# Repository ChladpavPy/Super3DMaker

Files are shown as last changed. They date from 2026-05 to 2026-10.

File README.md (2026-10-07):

# Super3DMaker Controller Board

So first I want to explain, why I started this project. I had an old Profi3DMaker 3D printer at home, which was not used for a long time, mainly because of the hardware, which was just outdated. Because the printer had electronics probably from years like 2012 and older, it was my idea to bring it again to life, because the tech of 3D printing and electronics changed a lot. The 3D printer actually works, but does not stand a chance to modern machines which would be even cheaper based on the materials. Back in 2012, this printer was high-end and one of the most expensive 3D printers, you could get, because of the high quality aluminium frame, but because the technology changed so rapidly, it is just unreliable and prints items badly now, when compared to new 3d printers, which are also cheap. And because it is mainly and electronics issue, I realized that I could build my own new 3D printer board for this 3D printer and bring it again to life, so I started new Project.

The first stage was actually reverse-engineering the old board and studying as much possible of how modern 3d printers work.

A custom mainboard designed to replace the old electronics in my 3D printer. Built to handle klipper high speed kinematics and communicate directly with a Raspberry Pi Zero 2W. Designed entirely from scratch in KiCad 10.

## The Build and Integration Phase

After receiving the manufactured PCB from JLCPCB, the project transitioned into the physical build phase. This involved soldering all components and integrating the new board into the chassis. 

The most intensive part was the software setup and calibration. I configured Klipper and the Raspberry Pi, and spent a significant amount of time getting the `printer.cfg` right. This meant dialing in the correct motor parameters, gear ratios, and microsteps through trial and error and reverse engineering.

### Results and Current Limitations

The custom STM32F407VET6 board works perfectly and successfully replaces the old ATmega setup. Klipper brings many modern features compared to the old Marlin firmware. Thanks to the new TMC2209 drivers, the printer is now significantly quieter during operation.

However, the build process revealed several mechanical limitations of the original Profi3DMaker chassis that the new electronics alone cannot fix:
* **Z-Axis Noise:** Despite the silent drivers, the Z-axis still makes mechanical grinding noises, indicating a physical issue with the leadscrews or bearings.
* **Heated Bed Inefficiency:** The massive original heated bed takes around an hour to reach just 70°C. 
* **Toolhead Weight:** The older extruder system is extremely heavy, limiting printing speeds and precision. 

To fully utilize the new controller board's capabilities, I have designed a completely new mount for a modern toolhead. This can be actually directly mounted on the chassis. However, this will only add weight if I don't disassemble the moving carriage from the tubes, which requires practically disassembling the entire printer, which I plan to do as a future upgrade. This would also require creating another model which would replace the previous aluminium carriage on the tubes. For now, the goal of successfully designing, building, and running a custom controller board has been achieved.

## Firmware

Since this board is built around a custom STM32F407VET6 microcontroller, it runs on the open-source [Klipper](https://github.com/Klipper3d/klipper) firmware. Instead of writing custom kinematic calculations from scratch, the firmware setup uses a printer configuration file. You can find the complete pin-mapping and configuration file (`printer.cfg`), along with the original dumped `.srec` firmware files used to reverse-engineer the correct gear ratios and microsteps, ready in the `Firmware` folder. You can also access all the other original files for this 3D printer by registering on the 3D Factories website.
## Project Features

* **Microcontroller:** STM32F407VET6 (100-pin, 32-bit ARM Cortex-M4)
* **Stackup:** 4-Layer PCB (Signal / GND / GND / Signal) for internal routing and better EMI shielding
* **Stepper Drivers:** 6x UART-controlled TMC2209 sockets
* **Power:** 24V main input with dual LM2596S buck converters (5V and 3.3V rails)
* **Connectivity:** USB-B for main communication, native Raspberry Pi UART interface
* **Displays:** Standard 10-pin IDC EXP1 and EXP2 headers for legacy 12864 or modern SPI BTT Mini12864 displays
* **Hardware Interlock:** Laser module power logically tied to the high-current heated bed circuit to prevent simultaneous power draw

* And more other...

### Video Demos

https://github.com/user-attachments/assets/c8a4d6e0-8937-4ded-b093-ac17ca0ef771

https://github.com/user-attachments/assets/72c90019-3e0b-4c00-92d0-47ec632bfb1b

https://github.com/user-attachments/assets/8aad29d0-d306-4471-a87c-c93d6b09ec2d

LIS2DW accelometer calibration

https://github.com/user-attachments/assets/c06aa969-909b-4192-8ba1-088b3594a9f0

CR Touch Bed Mesh

https://github.com/user-attachments/assets/029f4fde-3b9d-4758-a506-7faca7a6295e

## Gallery

### Build Preview
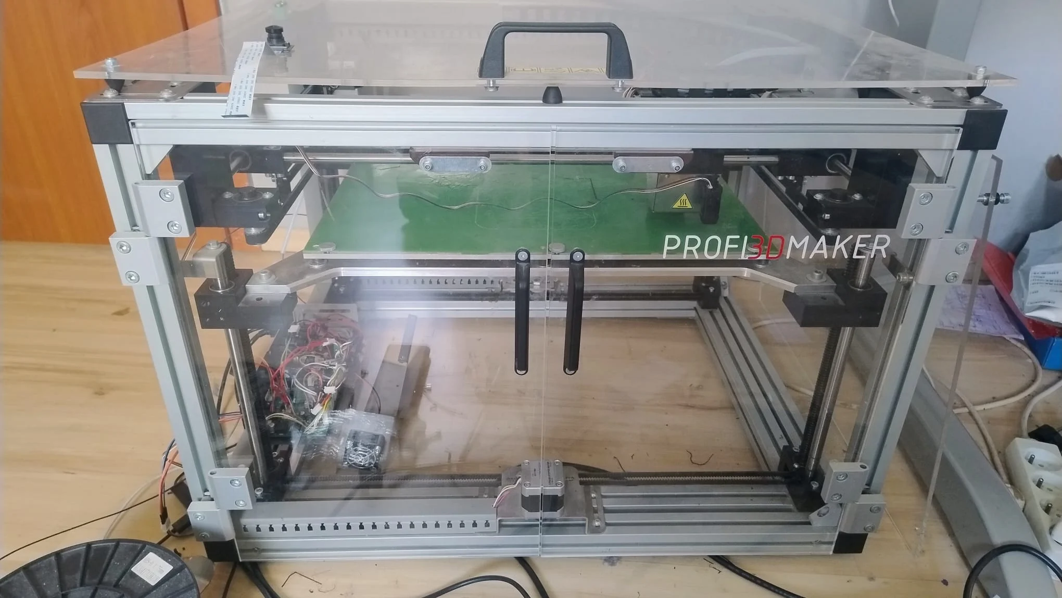
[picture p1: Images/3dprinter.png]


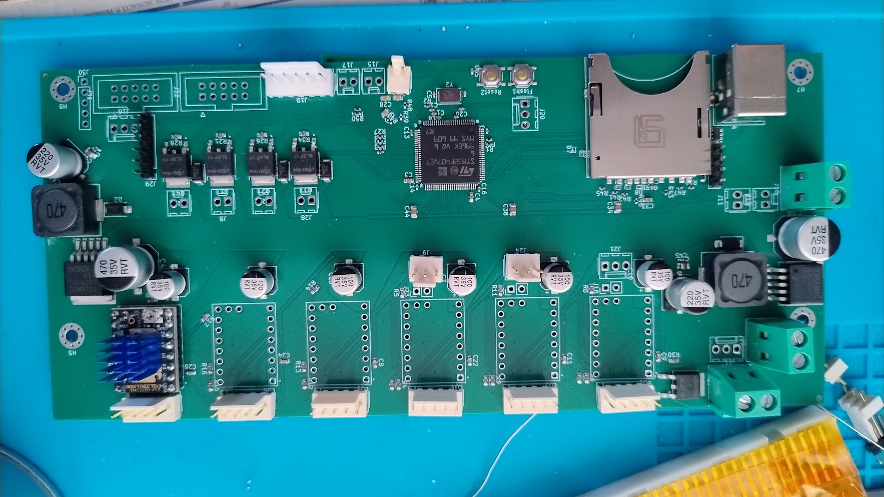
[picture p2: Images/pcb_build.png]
Build Preview


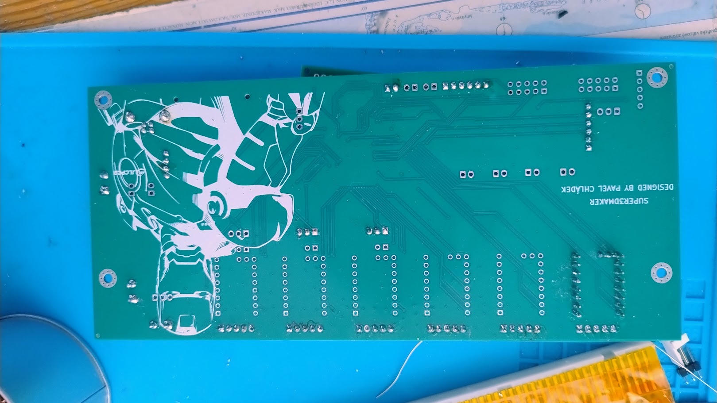
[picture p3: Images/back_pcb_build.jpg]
Build Preview


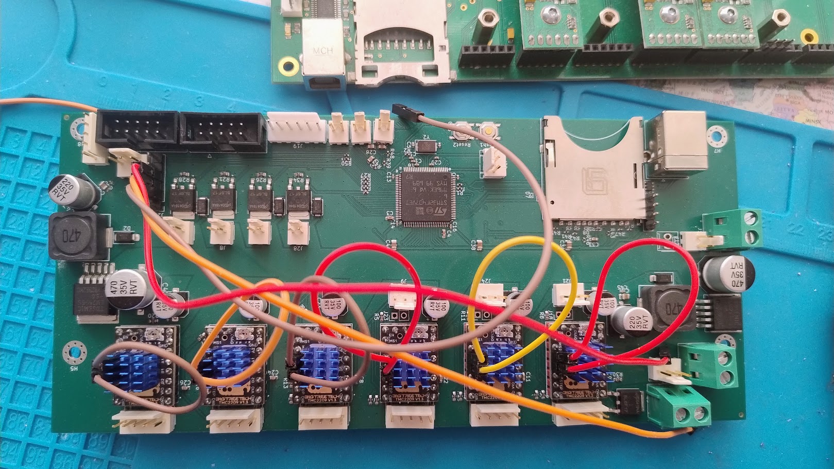
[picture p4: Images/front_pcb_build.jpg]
Build Preview


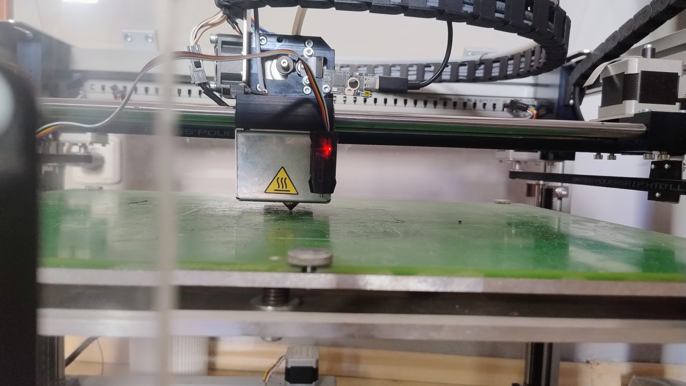
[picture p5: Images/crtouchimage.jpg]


### Printing
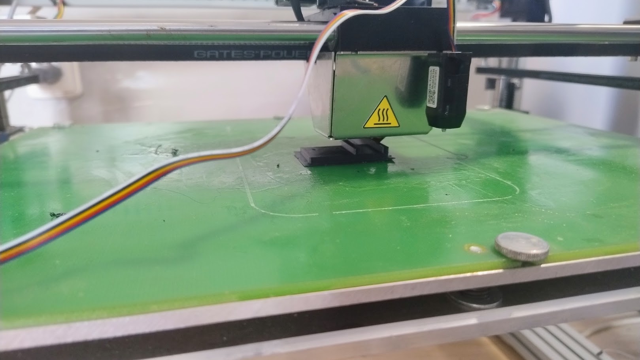
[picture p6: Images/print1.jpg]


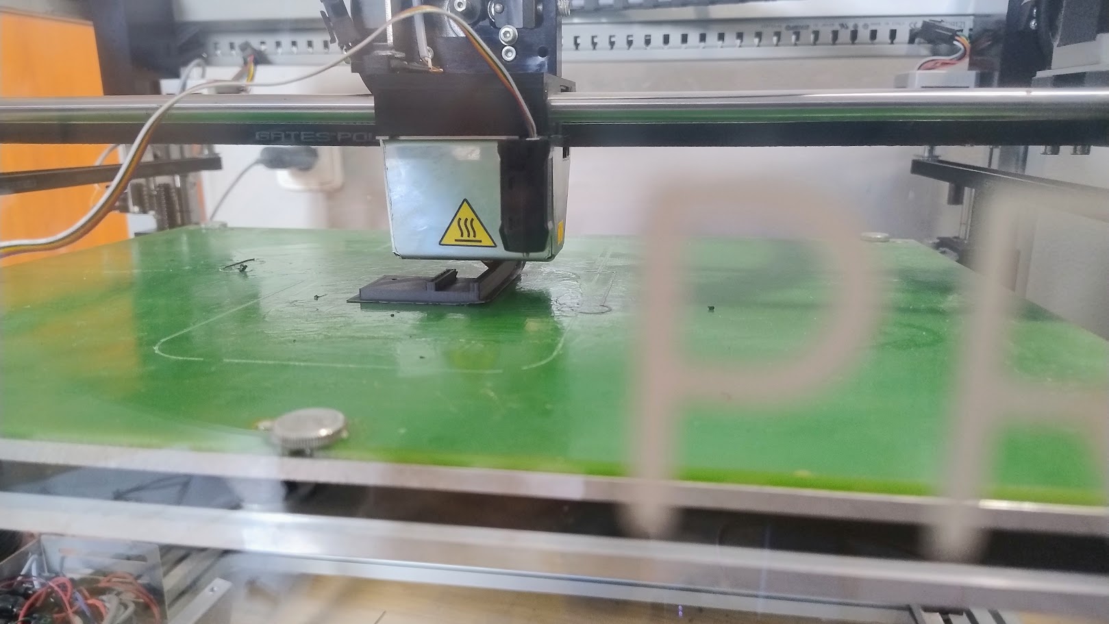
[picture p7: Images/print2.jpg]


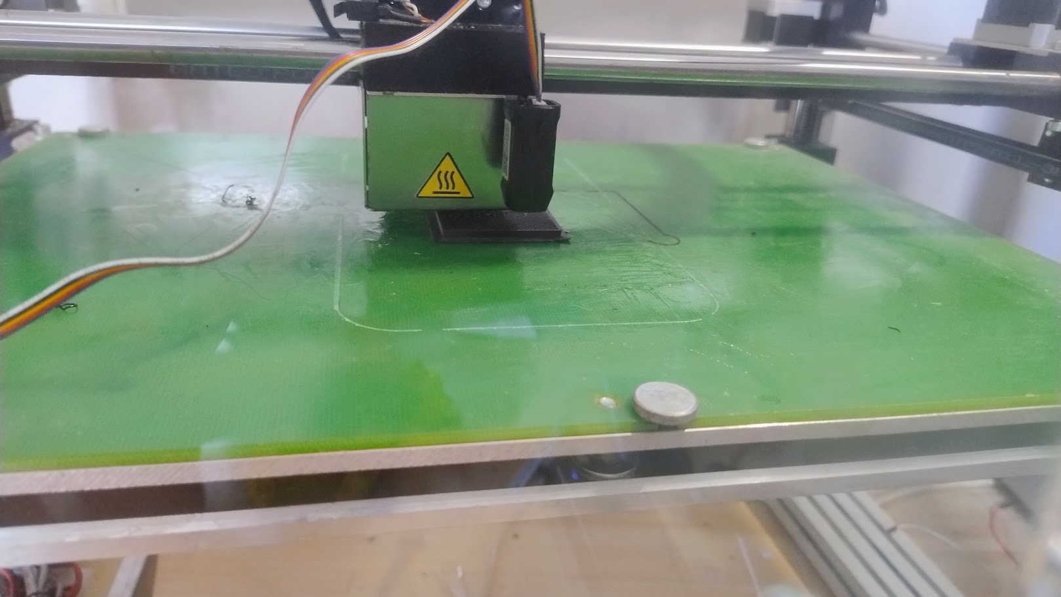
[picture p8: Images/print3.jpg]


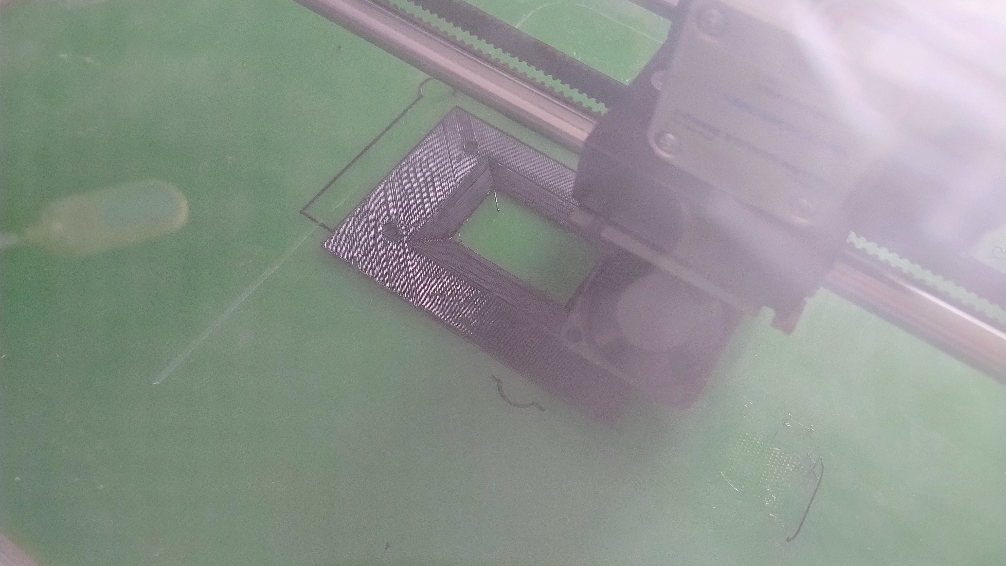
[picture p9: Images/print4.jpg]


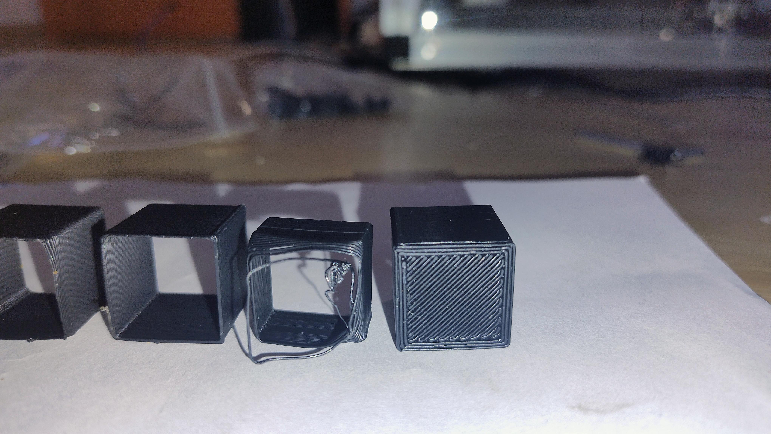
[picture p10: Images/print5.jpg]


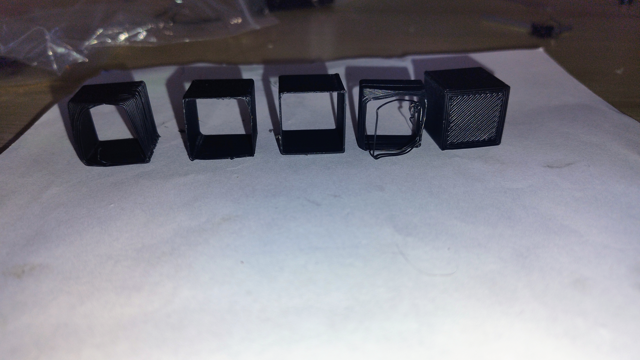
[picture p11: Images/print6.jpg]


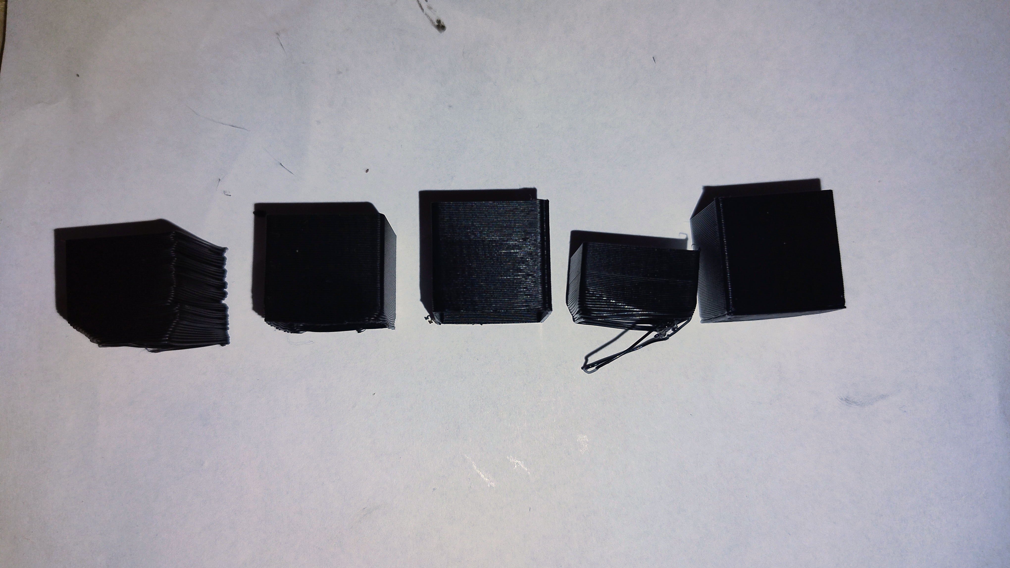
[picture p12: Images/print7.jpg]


### 3D PCB Render
PCB 3D

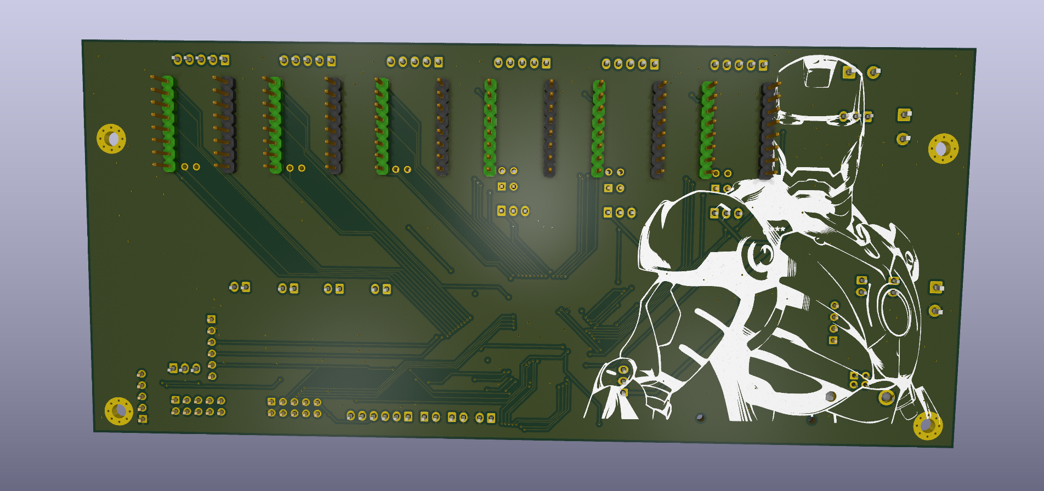
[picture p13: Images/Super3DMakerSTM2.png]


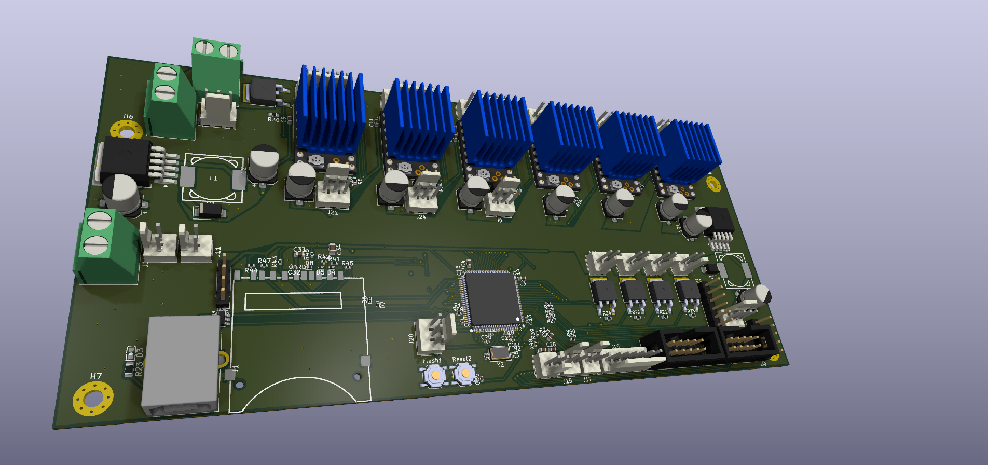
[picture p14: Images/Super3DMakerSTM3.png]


### PCB Routing
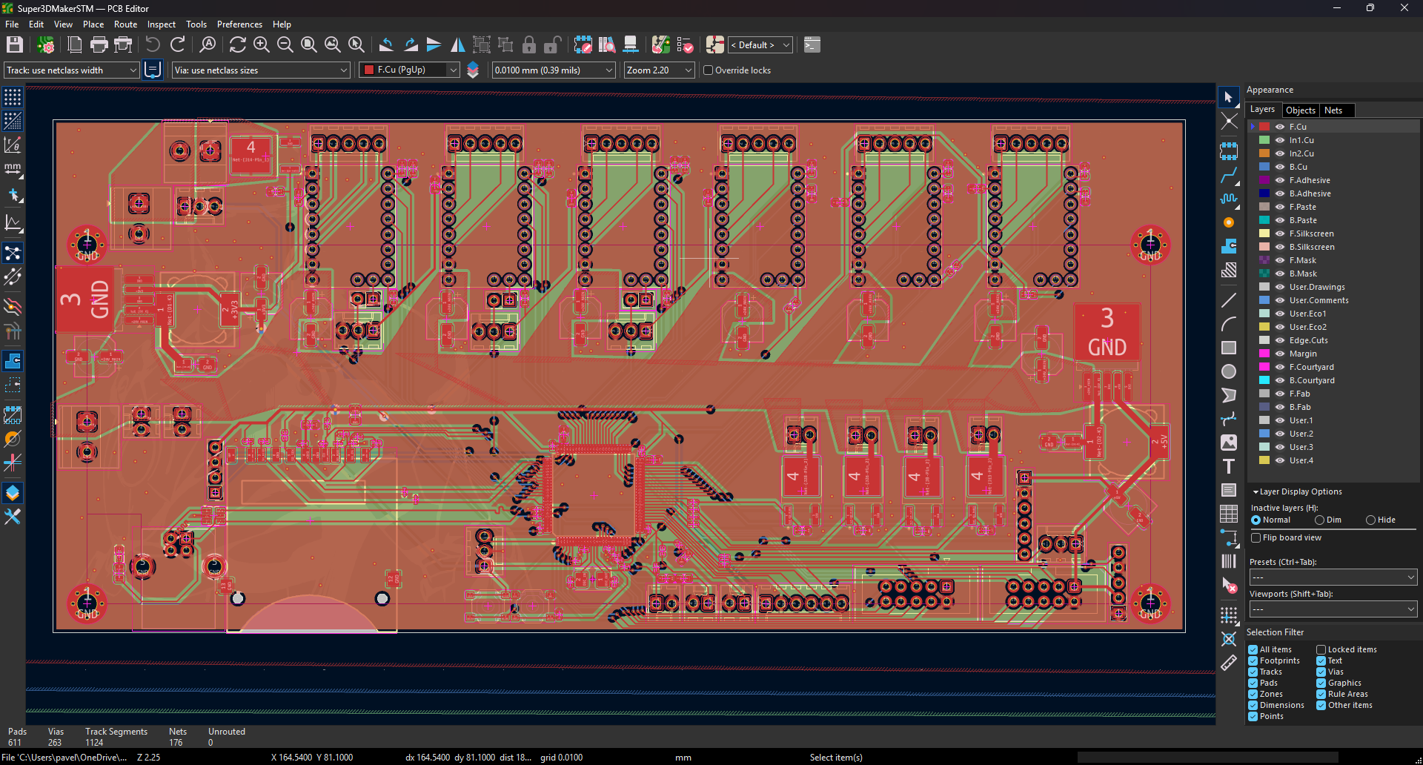
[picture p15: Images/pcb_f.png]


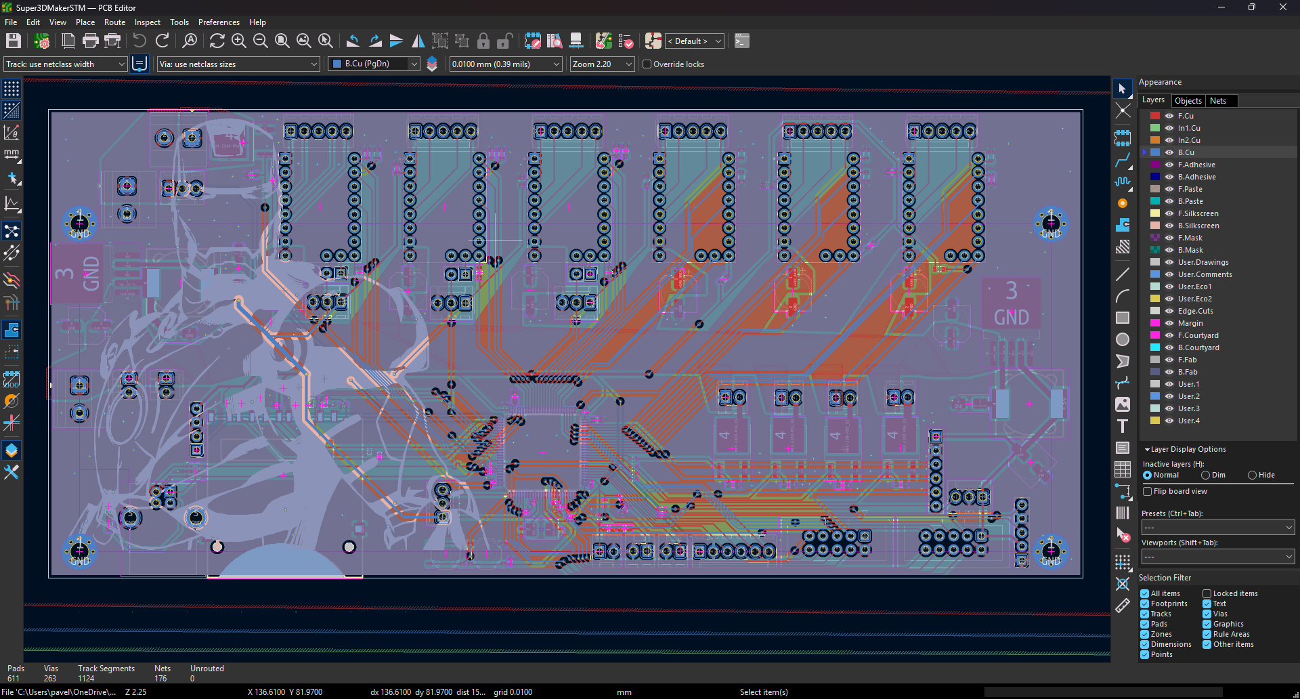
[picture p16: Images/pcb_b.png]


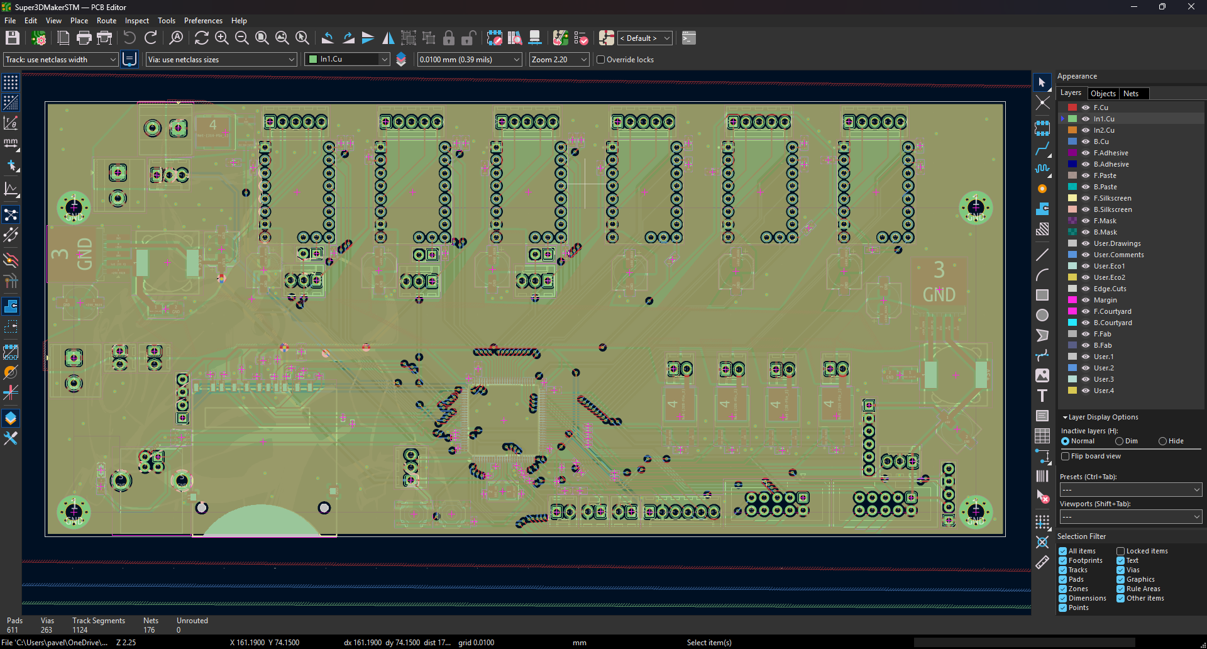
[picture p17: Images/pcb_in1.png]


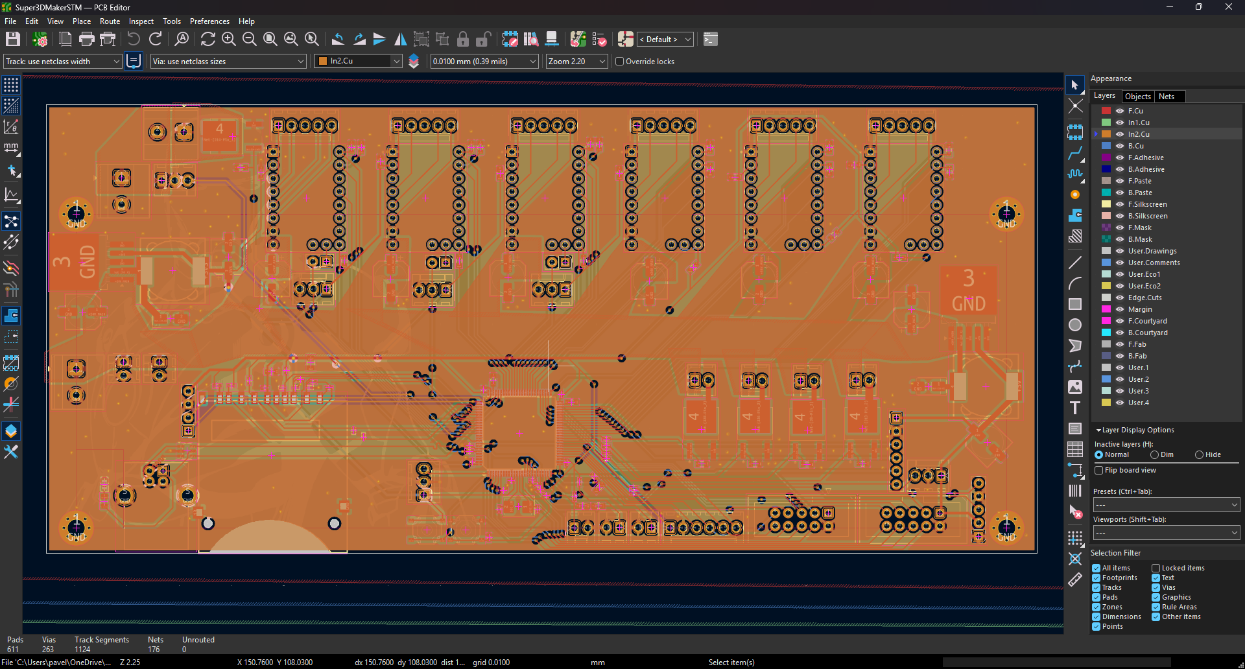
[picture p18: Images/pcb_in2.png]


### Schematic
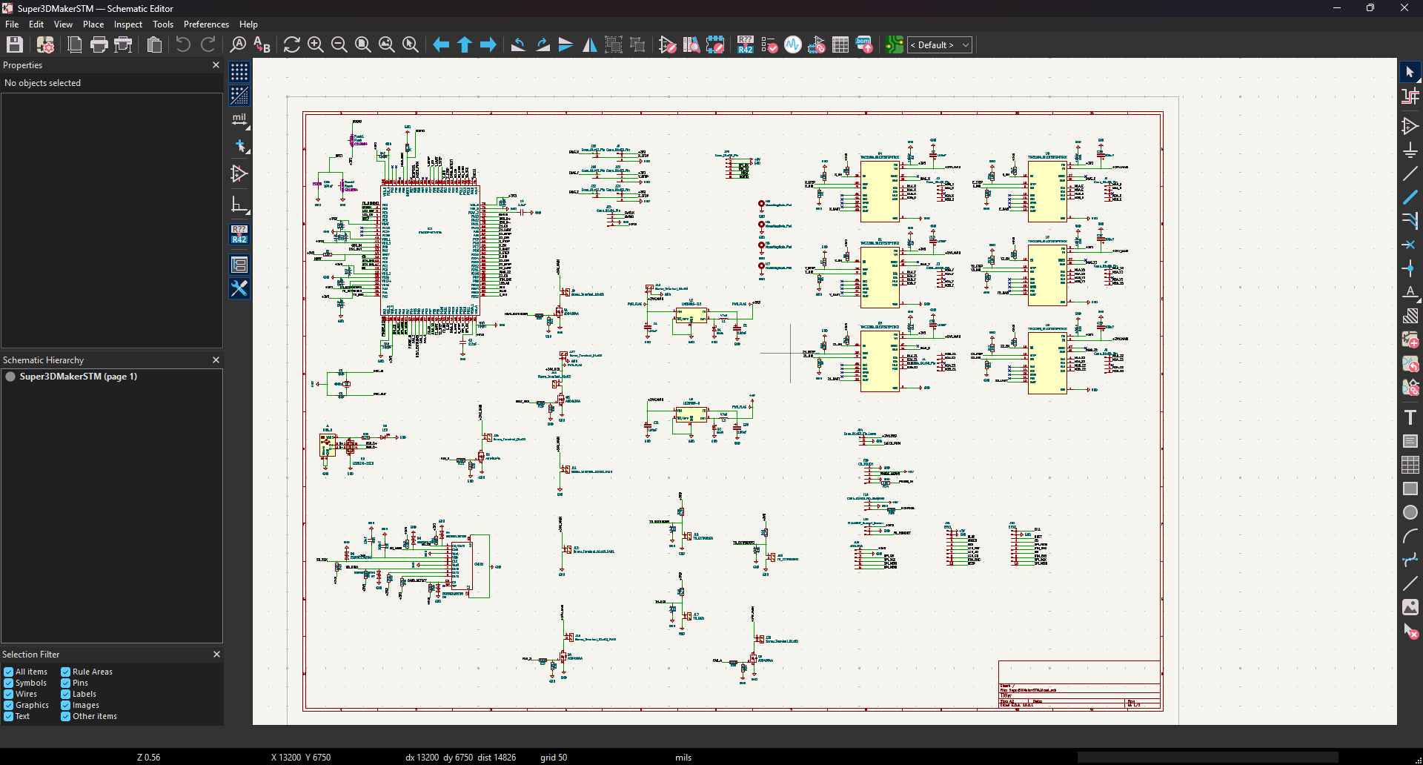
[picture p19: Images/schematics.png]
Schematic


---

## Bill of Materials (BOM)

| Component | Qty | Purpose / Description | Price (USD) | Link / Distributor |
| :--- | :---: | :--- | :--- | :--- |
| **Custom PCBA (Mainboard)** | 2 | Custom designed 4-layer STM32 controller board. Fully assembled via JLCPCB SMT (minus the THT USB-B connector which will be soldered manually to avoid mechanical case collisions). | ~$137.67 | JLCPCB - This is the price for 2 assembled boards to keep the price as low as possible. |
| **BIQU H2 V2S REVO** | 1 | Ultra-lightweight direct drive extrusion system with rapid-change nozzle capability. Replaces the current heavy toolhead, significantly reducing weight on the massive 400mm X-axis for faster, vibration-free printing. | $151.45 | [Allegro](https://allegro.cz/produkt/extruder-btt-biqu-h2-v2s-revo-direct-drive-1-75-mm-ce63ae7c-46b2-4eb6-95d3-a286495341f3?offerId=12801178318) |
| **ADXL345 3-Axis Accelerometer** | 2 | Essential for Klipper's Input Shaping calibration. It measures the physical resonance frequencies of the X and Y axes, allowing the firmware to actively cancel out vibrations during high-speed printing and eliminate ringing/ghosting on the printed parts. | $2.88 | [AliExpress](https://a.aliexpress.com/_EH7aAa2) |
| **CR-Touch (Auto Bed Leveling)** | 1 | Provides automatic high-precision mesh bed leveling. It compensates for any slight warping of the print bed and ensures a perfect first layer every time by measuring the distance between the nozzle and the build surface at multiple points. | $20.00 | [AliExpress](https://a.aliexpress.com/_EvwN6HC) |
| **BigTreeTech TMC2209 V1.3** | 6 | These are high-performance silent motor drivers required for the custom motherboard. They feature StealthChop technology for near-silent operation and StallGuard for sensorless homing, eliminating the need for physical limit switches. | $19.25 | [AliExpress](https://a.aliexpress.com/_EILgKrG) |
| **Raspberry Pi Zero 2W** | 1 | Serves as the main host computer for the custom 3D printer. It runs the Klipper firmware ecosystem and its web interface (Mainsail/Fluidd), performs heavy kinematics calculations, and sends precise hardware commands to the custom-designed STM32 motherboard via serial/USB connection. | $20.17 | [Rpishop](https://rpishop.cz/raspberry-pi-zero/4311-raspberry-pi-zero-2-w.html) |

### Mechanical and Assembly

| Item | Qty | Specification | Purpose |
| :--- | :---: | :--- | :--- |
| **Original Aluminum Case** | 1 | The heavy original printer chassis | I had to reverse engineer the mounting holes and connector distances, because I could not get the original CAD files. It was a nightmare but it fits within like 4.7mm of the board edge now. |
| **M3 Screws** | 4 | Standard mounting hardware | Securing the PCB to the chassis standoffs. |
- For the case of the 3d printer - Profi3DMaker case is used

## How to Build and Flash Firmware

If you want to replicate this custom controller board for your own Profi3DMaker or similar 3D printer, follow these steps:

1. **PCB Fabrication & Assembly:** Use the provided Gerber files (found in the repository) to manufacture the board. Most SMD components are assembled by JLCPCB, but you will need to manually solder the THT USB-B connector, terminal blocks, and JST headers.
2. **STM32 Bootloader & Klipper Firmware:**
   * Connect the board to your PC via USB-B while holding the BOOT/RESET buttons to enter DFU mode.
   * Compile Klipper for the `STM32F407VET6` chip using `make menuconfig` on your Raspberry Pi Zero 2W.
   * Flash the compiled `klipper.bin` to the STM32 using STM32CubeProgrammer.
3. **Raspberry Pi Integration:** Connect the Raspberry Pi Zero 2W to the board using the dedicated UART pins for serial communication.
4. **Configuration:** Upload the provided `printer.cfg` (found in the `/Firmware` folder) to your Klipper interface (Mainsail/Fluidd) and verify motor directions and sensor readings.
That is all, thank you for reading!

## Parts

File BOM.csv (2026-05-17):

Reference | Qty | Value | DNP | Exclude from BOM | Exclude from Board | Footprint | Datasheet | MNF PART NUMBER | LCSC
C1,C2,C7,C10,C21,C23,C25,C27,C30,C31 | 10 | 100uF |  |  |  | Capacitor_SMD:CP_Elec_6.3x7.7 |  | C3352 | C3352
C3,C4 | 2 | 2.2uF |  |  |  | Capacitor_SMD:C_0603_1608Metric |  | C23630 | C23630
C5,C6 | 2 | 33pF |  |  |  | Capacitor_SMD:C_0402_1005Metric |  | C1562 | C1562
C8,C9,C11,C22,C24,C26 | 6 | 100nF |  |  |  | Capacitor_SMD:C_0603_1608Metric |  | C14663 | C14663
C12,C13,C14,C15,C16,C17,C18,C19,C20 | 9 | 100nF |  |  |  | Capacitor_SMD:C_0402_1005Metric |  | C307331 | C307331
C28,C29,C36 | 3 | 10uF |  |  |  | Capacitor_SMD:C_0603_1608Metric |  | C14663 | C14663
C32 | 1 | 100nF |  |  |  | Capacitor_SMD:C_0402_1005Metric |  | C14663 | C14663
C33 | 1 | 10uF |  |  |  | Capacitor_SMD:C_0603_1608Metric |  | C19702 | C19702
C34 | 1 | 10uF |  |  |  | Capacitor_SMD:C_0805_2012Metric |  | C14663 | C14663
C35 | 1 | 100nF |  |  |  | Capacitor_SMD:C_0402_1005Metric |  | C1525 | C1525
CARD1 | 1 | SD_CARD |  |  |  | Moje_knihovna:SD_KARTA_OPRAVENA | https://item.szlcsc.com/datasheet/SD-006M/136893.html | C125615 | C125615
D1,D2 | 2 | SS54 |  |  |  | Diode_SMD:D_SMA |  | C22452 | C22452
D3 | 1 | LED |  |  |  | LED_SMD:LED0603-RD |  | C2286 | C2286
D4,D5,D6,D7,D8 | 5 | ESD9B3.3ST5G |  |  |  | Diode_SMD:D_SOD-923 | https://www.onsemi.com/pub/Collateral/ESD9B-D.PDF | C96512 | C96512
Flash1 | 1 | Flash |  |  |  | Button_Switch_SMD:SW_Push_1P1T_XKB_TS-1187A |  | C318884 | C318884
IC1 | 1 | STM32F407VET6 |  |  |  | Moje_knihovna:LQFP100-0.5-13.8X13.8MM | https://www.st.com/resource/en/datasheet/stm32f405zg.pdf | C28730 | C28730
J1 | 1 | USB_B |  |  |  | Connector_USB:USB_B_OST_USB-B1HSxx_Horizontal |  | C498173 | C498173
J2,J3,J4,J5,J6,J7 | 6 | Conn_01x05_Pin |  |  |  | Connector_Molex:Molex_KK-254_AE-6410-05A_1x05_P2.54mm_Vertical
J8,J26,J28 | 3 | Screw_Terminal_01x02 |  |  |  | Connector_Molex:Molex_KK-254_AE-6410-02A_1x02_P2.54mm_Vertical
J9,J21,J24 | 3 | Conn_01x03_Pin |  |  |  | Connector_Molex:Molex_KK-254_AE-6410-03A_1x03_P2.54mm_Vertical
J10,J14,J27 | 3 | Screw_Terminal_01x02 |  |  |  | TerminalBlock_Phoenix:TerminalBlock_Phoenix_MKDS-1 | 5-2-5.08_1x02_P5.08mm_Horizontal
J11 | 1 | Screw_Terminal_01x02_FAN0 |  |  |  | Connector_Molex:Molex_KK-254_AE-6410-02A_1x02_P2.54mm_Vertical
J12 | 1 | Screw_Terminal_01x02_FAN1 |  |  |  | Connector_Molex:Molex_KK-254_AE-6410-02A_1x02_P2.54mm_Vertical
J13 | 1 | Screw_Terminal_01x02_FAN2 |  |  |  | Connector_Molex:Molex_KK-254_AE-6410-02A_1x02_P2.54mm_Vertical
J15 | 1 | TH_EXTRUDER |  |  |  | Connector_Molex:Molex_KK-254_AE-6410-02A_1x02_P2.54mm_Vertical
J16 | 1 | Conn_01x03_Pin_Neopixel |  |  |  | Connector_Molex:Molex_KK-254_AE-6410-03A_1x03_P2.54mm_Vertical
J17 | 1 | TH_BED |  |  |  | Connector_Molex:Molex_KK-254_AE-6410-02A_1x02_P2.54mm_Vertical
J18,J22,J23 | 3 | Conn_01x02_Pin |  |  |  | Connector_PinHeader_2.54mm:PinHeader_1x02_P2.54mm_Vertical
J19 | 1 | ADXL345 |  |  |  | Connector_Molex:Molex_KK-254_AE-6410-06A_1x06_P2.54mm_Vertical
J20 | 1 | FILAMENT_Runout_Sensor |  |  |  | Connector_Molex:Molex_KK-254_AE-6410-03A_1x03_P2.54mm_Vertical
J25 | 1 | Conn_01x04_Pin |  |  |  | Connector_PinHeader_2.54mm:PinHeader_1x04_P2.54mm_Vertical
J29 | 1 | Conn_01x06_Pin |  |  |  | Connector_PinHeader_2.54mm:PinHeader_1x06_P2.54mm_Vertical
J30 | 1 | CR_TOUCH |  |  |  | Connector_PinHeader_2.54mm:PinHeader_1x05_P2.54mm_Vertical
J31 | 1 | EPX1 |  |  |  | Connector_IDC:IDC-Header_2x05_P2.54mm_Vertical
J32 | 1 | EPX2 |  |  |  | Connector_IDC:IDC-Header_2x05_P2.54mm_Vertical
J33 | 1 | TH_EXTRUDER2 |  |  |  | Connector_Molex:Molex_KK-254_AE-6410-02A_1x02_P2.54mm_Vertical
J34 | 1 | Conn_01x03_Pin_Laser |  |  |  | Connector_Molex:Molex_KK-254_AE-6410-03A_1x03_P2.54mm_Vertical
L1,L2 | 2 | 47uH |  |  |  | Inductor_SMD:IND-SMD_L12.3-W12.3 |  | C9906 | C9906
Q1,Q2,Q3,Q4,Q5 | 5 | AOD4184A |  |  |  | Moje_knihovna:DPAK228P994X240-4N |  | C99124 | C99124
R1,R2,R24,R41,R42,R43,R44,R45,R46,R47 | 10 | 10K |  |  |  | Resistor_SMD:R_0402_1005Metric |  | C25804 | C25804
R3,R4,R5,R6,R7,R8,R9,R10,R11,R12,R13,R14,R15,R16,R17,R18,R19,R20,R21,R26,R28,R30,R34 | 23 | 10K |  |  |  | Resistor_SMD:R_0603_1608Metric |  | C25804 | C25804
R22,R25,R27,R29,R33,R50 | 6 | 330R |  |  |  | Resistor_SMD:R_0402_1005Metric |  | C25104 | C25104
R23 | 1 | 4.7K |  |  |  | Resistor_SMD:R_0805_2012Metric |  | C17673 | C17673
R39,R40,R48 | 3 | 4.7K |  |  |  | Resistor_SMD:R_0402_1005Metric |  | C25900 | C25900
Reset2 | 1 | Reset |  |  |  | Button_Switch_SMD:SW_Push_1P1T_XKB_TS-1187A |  | C318884 | C318884
U1,U3,U4,U5,U6,U7 | 6 | TMC2209_SILENTSTEPSTICK |  |  |  | Moje_knihovna:MODULE_TMC2209_SILENTSTEPSTICK
U2 | 1 | LM2596S-3.3 |  |  |  | Package_TO_SOT_SMD:TO-263-5_TabPin3 | http://www.ti.com/lit/ds/symlink/lm2596.pdf | C42421958 | C42421958
U8 | 1 | LM2596S-5 |  |  |  | Package_TO_SOT_SMD:TO-263-5_TabPin3 | http://www.ti.com/lit/ds/symlink/lm2596.pdf | C42421959 | C42421959
U9 | 1 | USBLC6-2SC6 |  |  |  | Package_TO_SOT_SMD:SOT-23-6 | https://www.st.com/resource/en/datasheet/usblc6-2.pdf | C7519 | C7519
Y2 | 1 | 8MHz |  |  |  | Crystal:Crystal_SMD_5032-2Pin_5.0x3.2mm |  | C115962 | C115962
H5,H6,H7,H8 | 4 | MountingHole |  |  |  | MountingHole_3.2mm_M3_Pad_Via

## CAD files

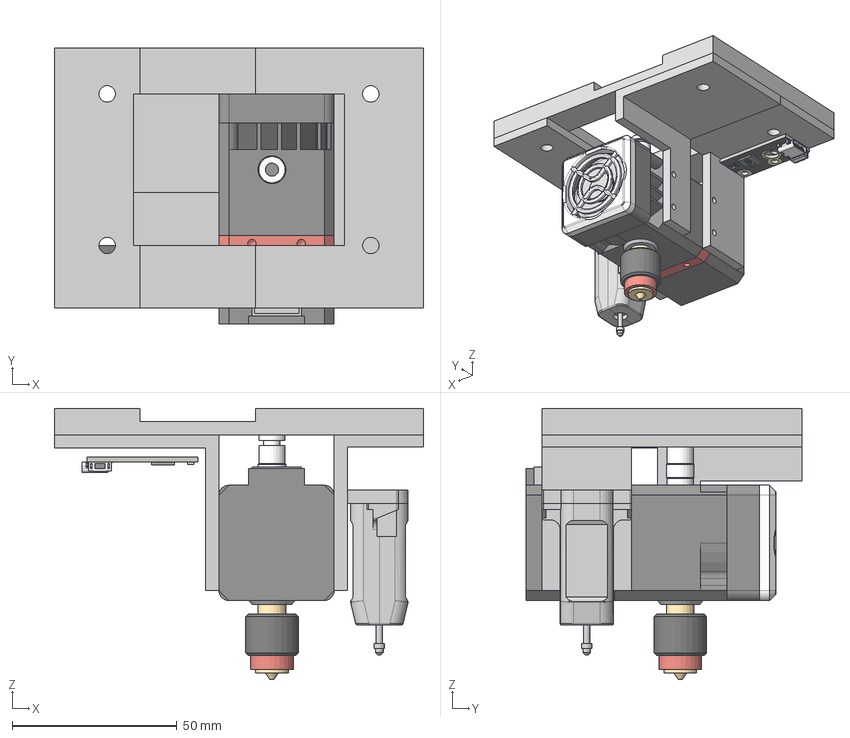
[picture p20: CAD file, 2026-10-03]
3D_Models/Super3dmaker_ToolheadV1.step
112.0 x 83.9 x 82.3 mm

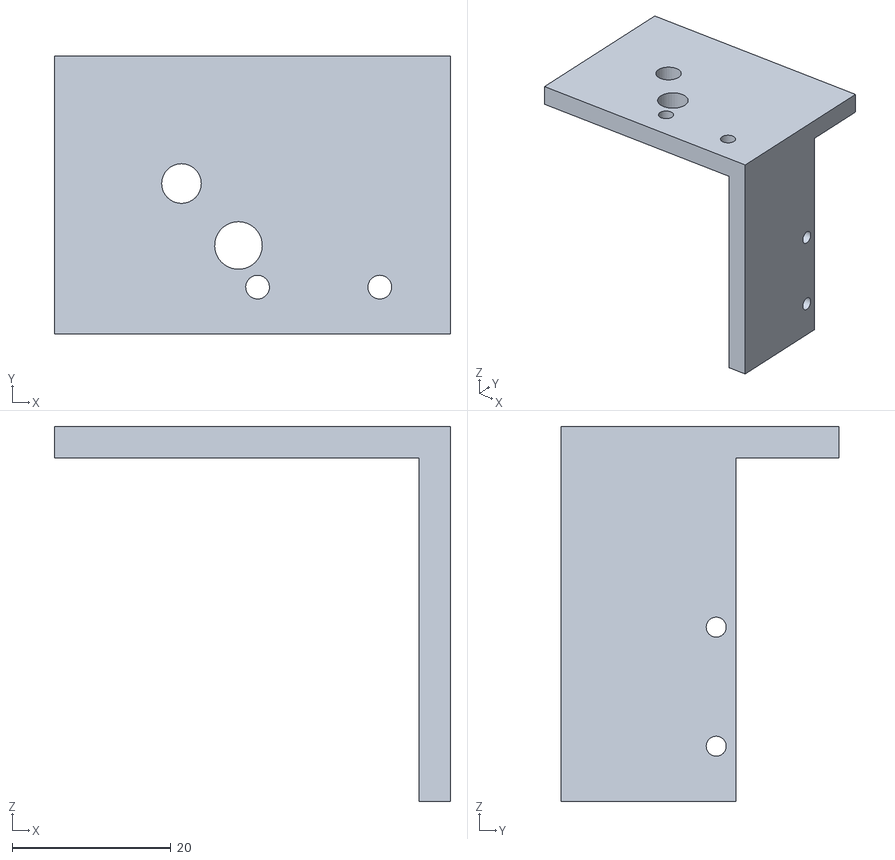
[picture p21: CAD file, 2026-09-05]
3D_Models/left_plate1.stl
49.9 x 35.1 x 47.3

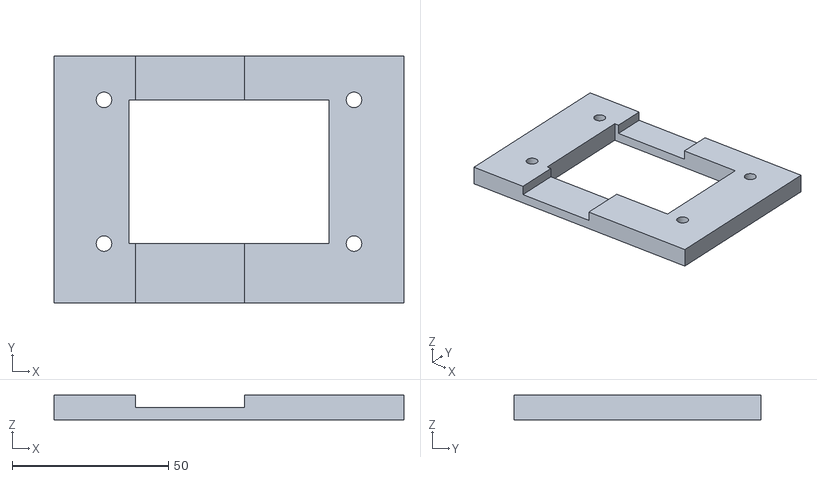
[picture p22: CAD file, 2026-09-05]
3D_Models/Top_plate.stl
112.0 x 79.0 x 8.00

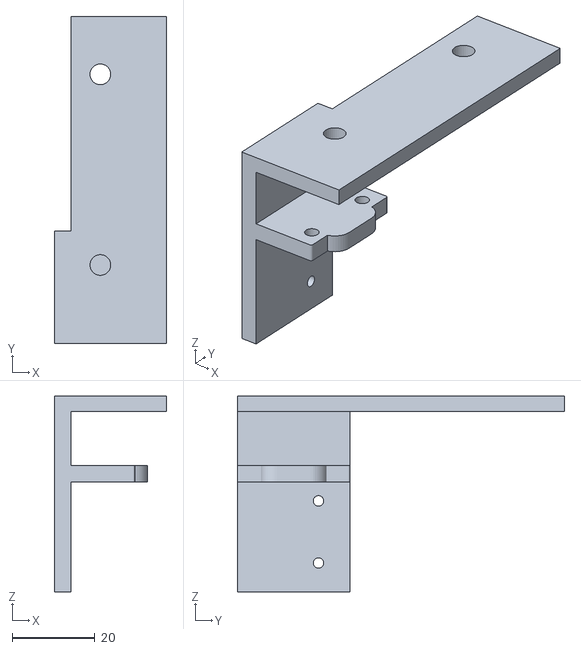
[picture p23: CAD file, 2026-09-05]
3D_Models/Right_plate.stl
27.1 x 79.0 x 47.3

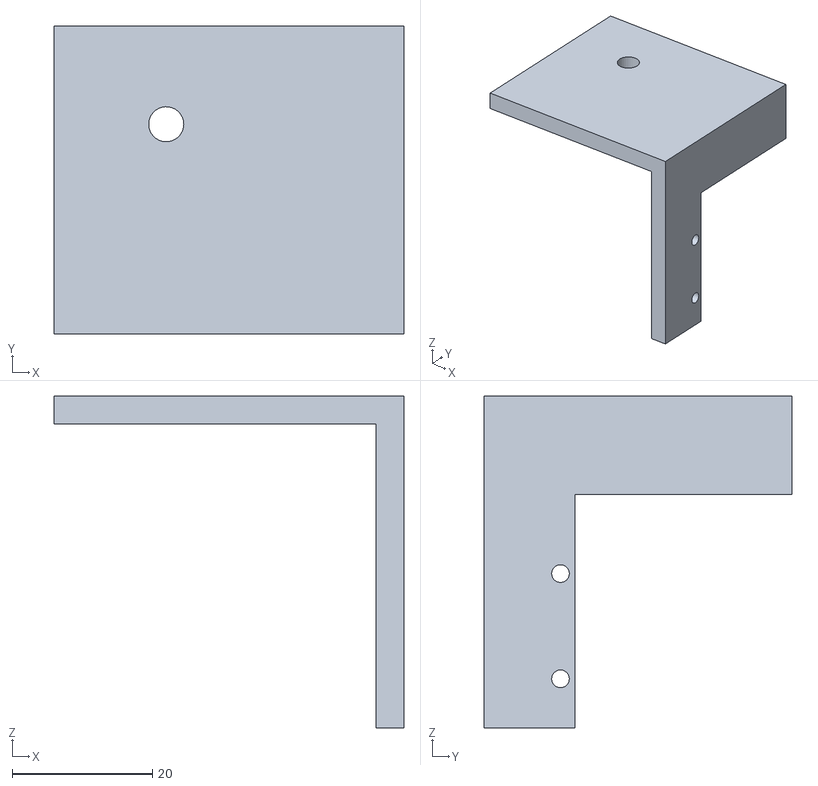
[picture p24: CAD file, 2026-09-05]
3D_Models/left_plate2.stl
49.9 x 43.9 x 47.3

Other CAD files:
3D_Models/Super3dmaker_ToolheadV1.f3z

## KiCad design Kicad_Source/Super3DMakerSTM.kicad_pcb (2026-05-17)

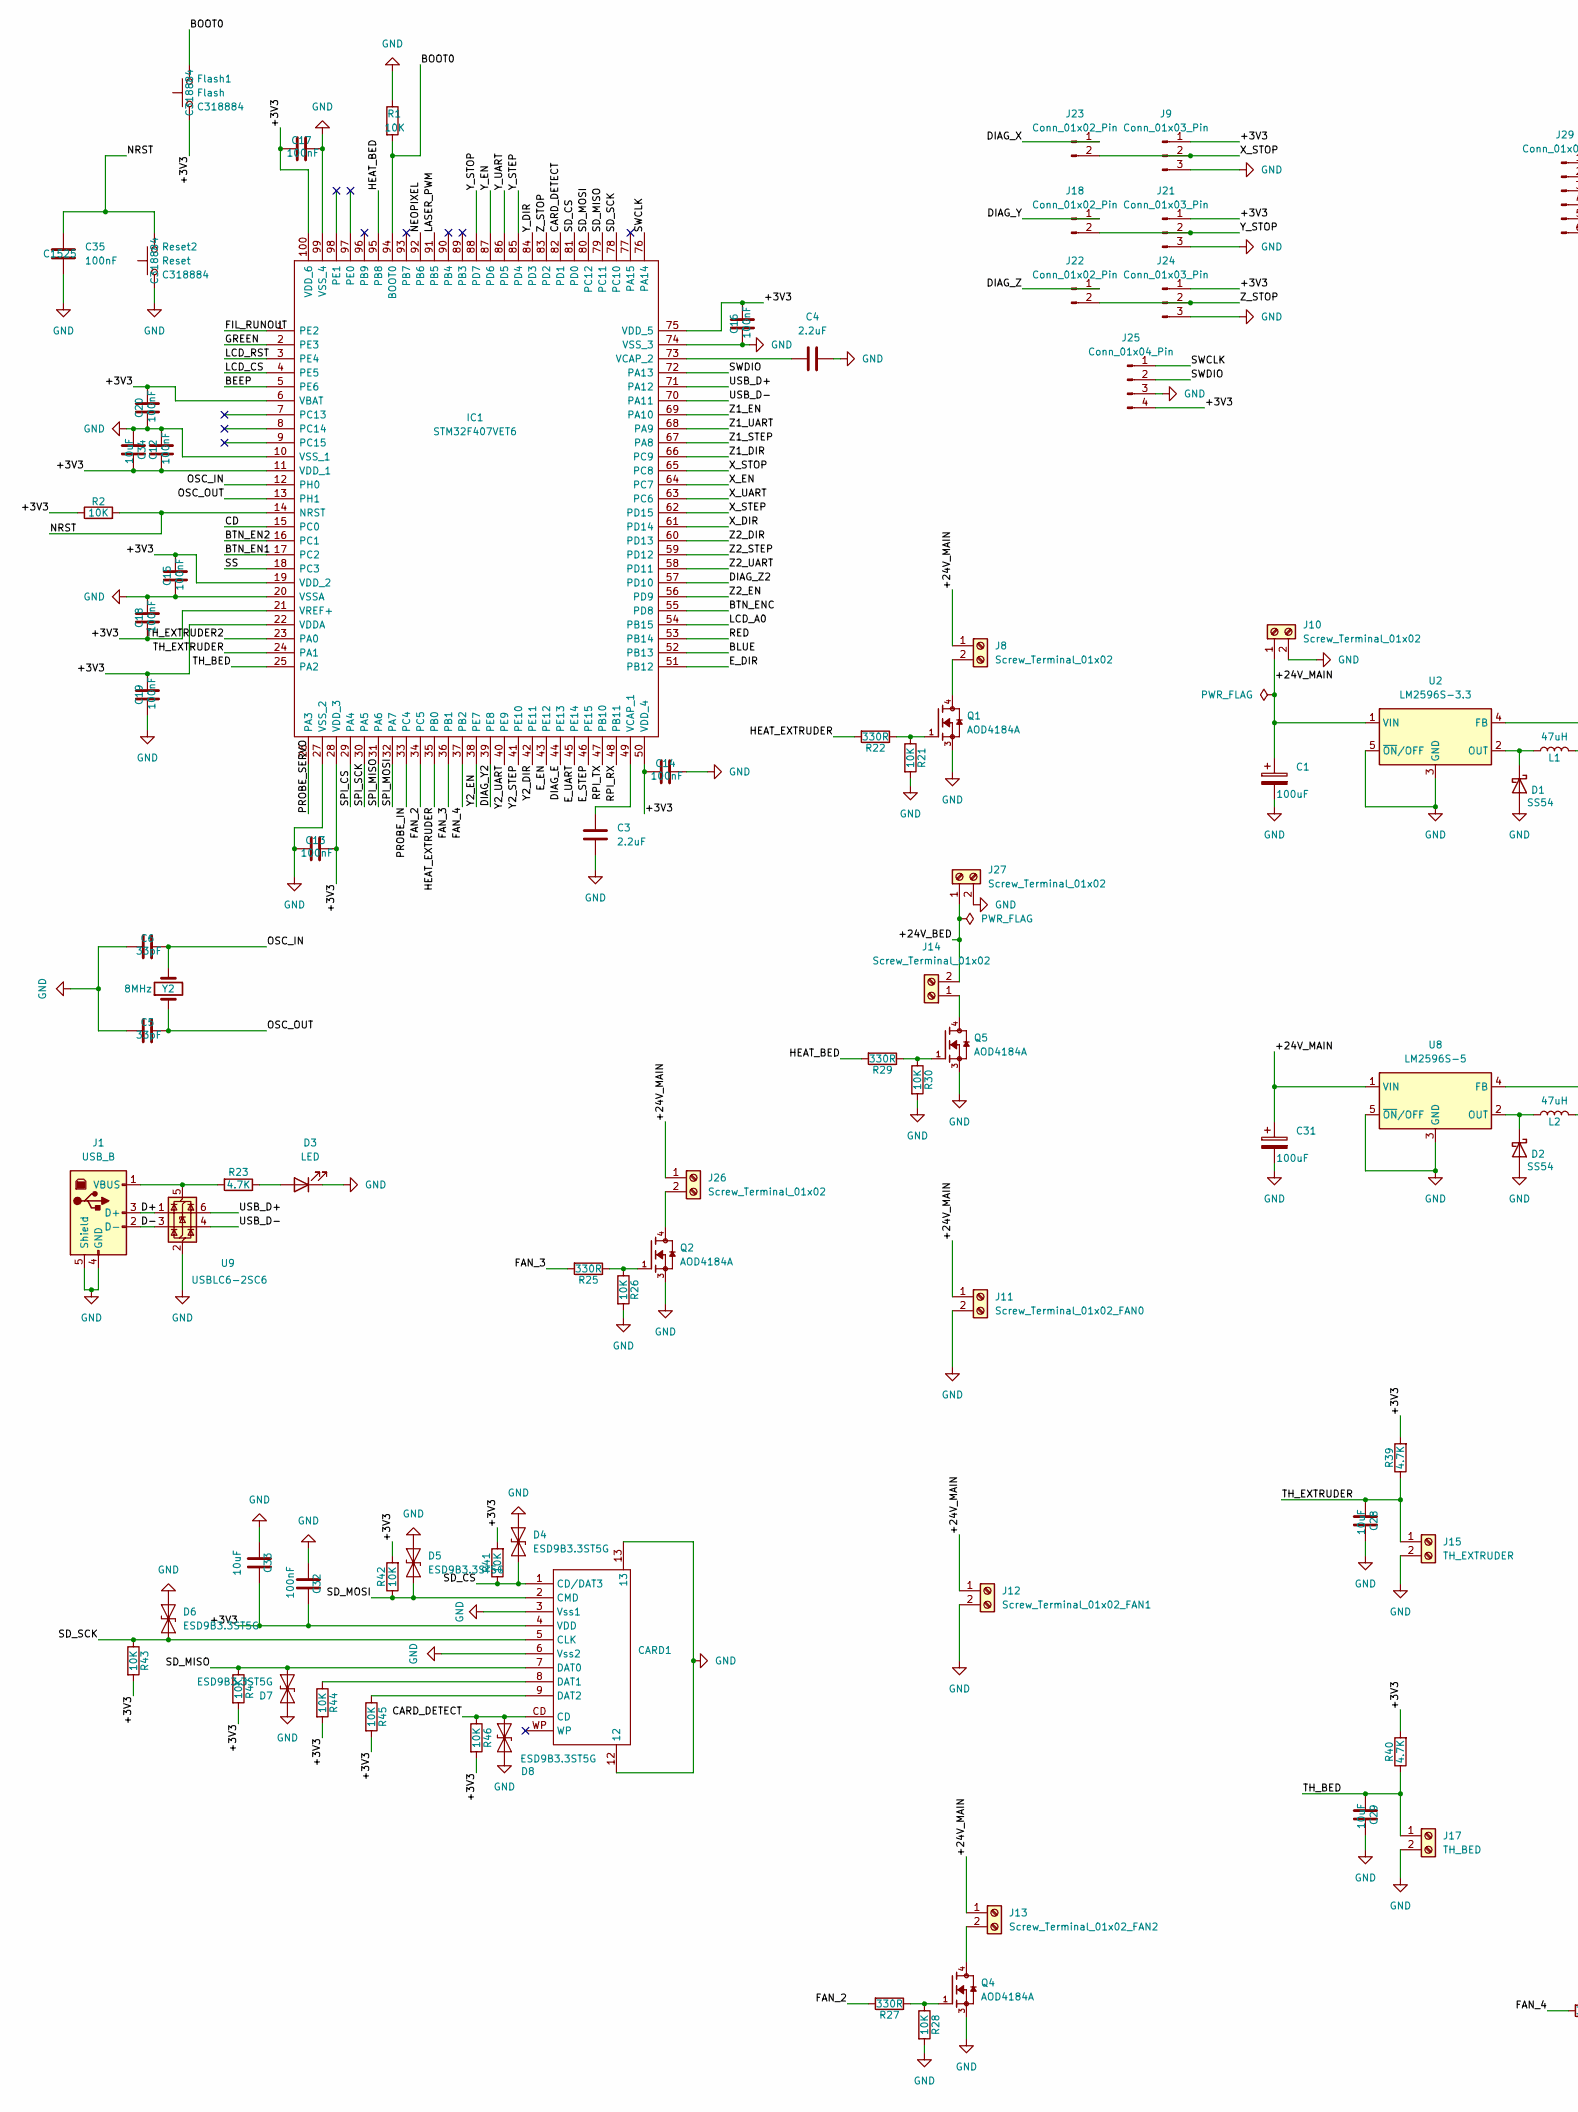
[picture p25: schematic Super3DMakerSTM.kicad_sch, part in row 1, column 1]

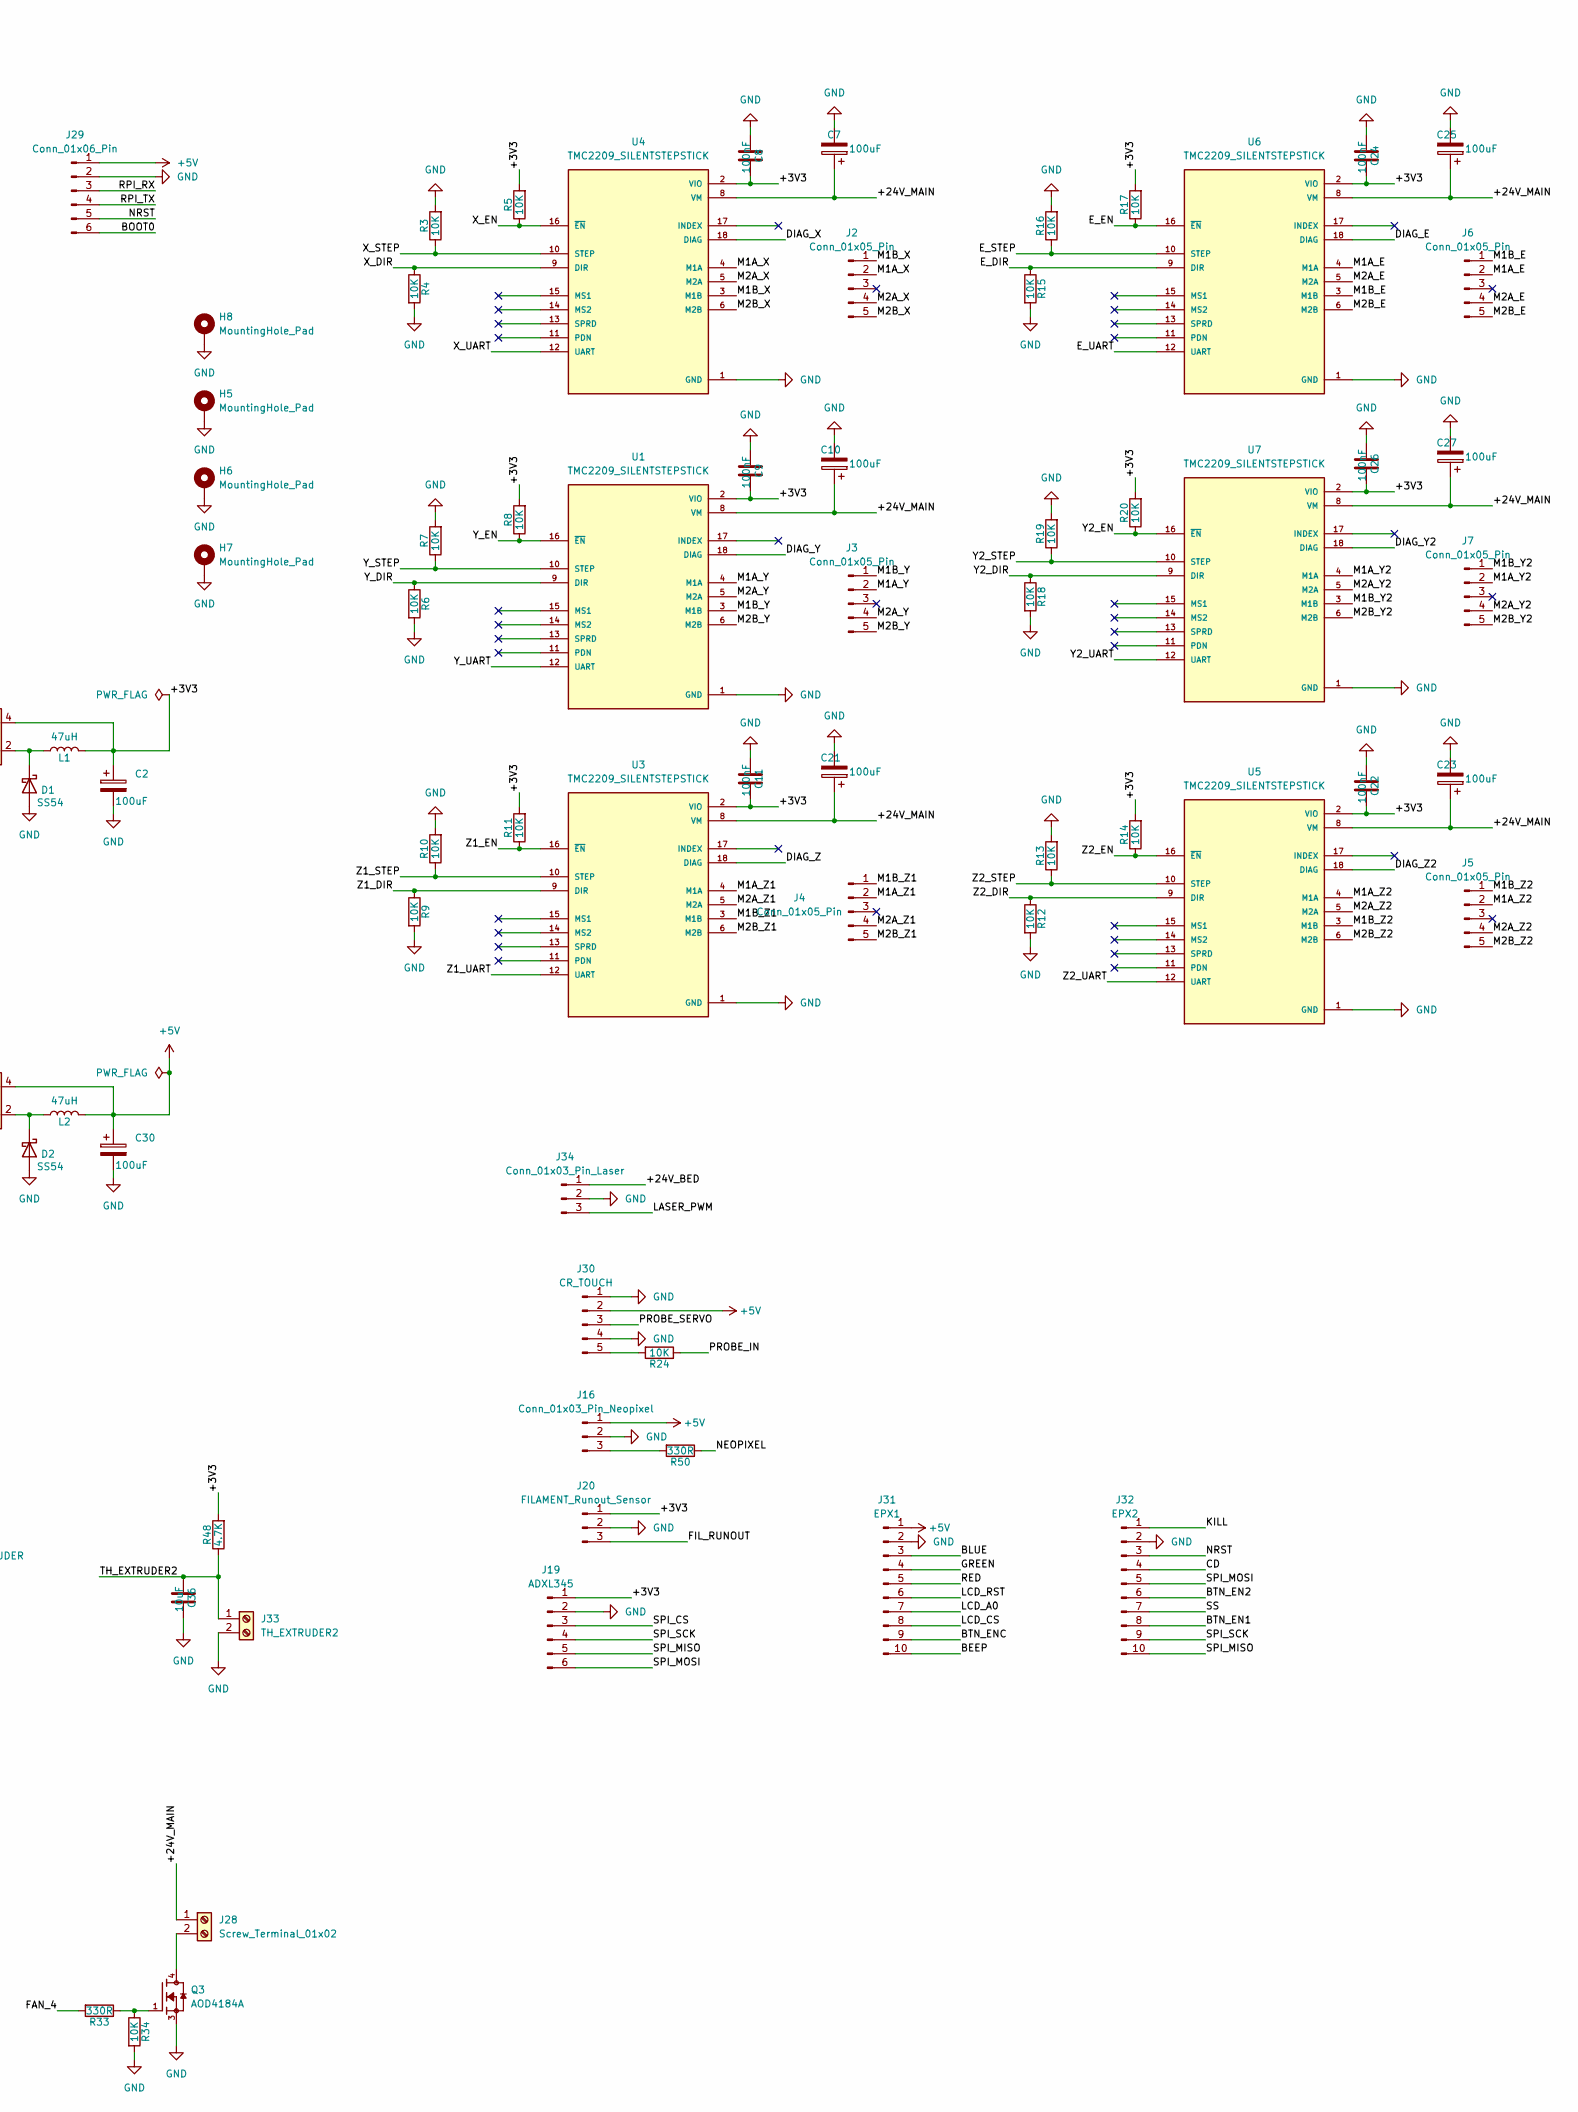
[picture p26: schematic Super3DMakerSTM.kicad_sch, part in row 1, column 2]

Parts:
C1, C2, C7, C10, C21, C23, C25, C27, C30, C31: 100uF; CP_Elec_6.3x7.7; LCSC C3352
C3, C4: 2.2uF; C_0603_1608Metric; LCSC C23630
C5, C6: 33pF; C_0402_1005Metric; LCSC C1562
C8, C9, C11, C22, C24, C26: 100nF; C_0603_1608Metric; LCSC C14663
C12, C13, C14, C15, C16, C17, C18, C19, C20: 100nF; C_0402_1005Metric; LCSC C307331
C28, C29, C36: 10uF; C_0603_1608Metric; LCSC C14663
C32: 100nF; C_0402_1005Metric; LCSC C14663
C33: 10uF; C_0603_1608Metric; LCSC C19702
C34: 10uF; C_0805_2012Metric; LCSC C14663
C35: 100nF; C_0402_1005Metric; MNF PART NUMBER C1525; LCSC C1525
CARD1: SD_KARTA_OPRAVENA; Manufacturer Part SD-006M; LCSC Part Name 自弹式 标准SD卡 卡座
D1, D2: SS54; D_SMA; LCSC C22452
D3: LED; LED0603-RD; LCSC C2286
D4, D5, D6, D7, D8: ESD9B3.3ST5G; D_SOD-923; LCSC C96512
Flash1: Flash; SW_Push_1P1T_XKB_TS-1187A; MNF PART NUMBER C318884; LCSC C318884
H5, H6, H7, H8: MountingHole_Pad; MountingHole_3.2mm_M3_Pad_Via
IC1: STM32F407VET6; LQFP100-0.5-13.8X13.8MM; Manufacturer_Part_Number STM32F407VET6; Mouser Part Number 511-STM32F407VET6
J1: USB_B; USB_B_OST_USB-B1HSxx_Horizontal; LCSC C498173
J2, J3, J4, J5, J6, J7: Conn_01x05_Pin; Molex_KK-254_AE-6410-05A_1x05_P2.54mm_Vertical
J8, J26, J28: Screw_Terminal_01x02; Molex_KK-254_AE-6410-02A_1x02_P2.54mm_Vertical
J9, J21, J24: Conn_01x03_Pin; Molex_KK-254_AE-6410-03A_1x03_P2.54mm_Vertical
J10, J14, J27: Screw_Terminal_01x02; TerminalBlock_Phoenix_MKDS-1,5-2-5.08_1x02_P5.08mm_Horizont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
J11: Screw_Terminal_01x02_FAN0; Molex_KK-254_AE-6410-02A_1x02_P2.54mm_Vertical
J12: Screw_Terminal_01x02_FAN1; Molex_KK-254_AE-6410-02A_1x02_P2.54mm_Vertical
J13: Screw_Terminal_01x02_FAN2; Molex_KK-254_AE-6410-02A_1x02_P2.54mm_Vertical
J15: TH_EXTRUDER; Molex_KK-254_AE-6410-02A_1x02_P2.54mm_Vertical
J16: Conn_01x03_Pin_Neopixel; Molex_KK-254_AE-6410-03A_1x03_P2.54mm_Vertical
J17: TH_BED; Molex_KK-254_AE-6410-02A_1x02_P2.54mm_Vertical
J18, J22, J23: Conn_01x02_Pin; PinHeader_1x02_P2.54mm_Vertical
J19: ADXL345; Molex_KK-254_AE-6410-06A_1x06_P2.54mm_Vertical
J20: FILAMENT_Runout_Sensor; Molex_KK-254_AE-6410-03A_1x03_P2.54mm_Vertical
J25: Conn_01x04_Pin; PinHeader_1x04_P2.54mm_Vertical
J29: Conn_01x06_Pin; PinHeader_1x06_P2.54mm_Vertical
J30: CR_TOUCH; PinHeader_1x05_P2.54mm_Vertical
J31: EPX1; IDC-Header_2x05_P2.54mm_Vertical
J32: EPX2; IDC-Header_2x05_P2.54mm_Vertical
J33: TH_EXTRUDER2; Molex_KK-254_AE-6410-02A_1x02_P2.54mm_Vertical
J34: Conn_01x03_Pin_Laser; Molex_KK-254_AE-6410-03A_1x03_P2.54mm_Vertical
L1, L2: 47uH; IND-SMD_L12.3-W12.3; MNF PART NUMBER C9906; LCSC C9906
Q1, Q2, Q3, Q4, Q5: AOD4184A; DPAK228P994X240-4N; PARTREV 0; LCSC C99124
R1, R2, R24, R41, R42, R43, R44, R45, R46, R47: 10K; R_0402_1005Metric; LCSC C25804
R3, R4, R5, R6, R7, R8, R9, R10, R11, R12, R13, R14, R15, R16, R17, R18, R19, R20, R21, R26, R28, R30, R34: 10K; R_0603_1608Metric; LCSC C25804
R22, R25, R27, R29, R33, R50: 330R; R_0402_1005Metric; LCSC C25104
R23: 4.7K; R_0805_2012Metric; LCSC C17673
R39, R40, R48: 4.7K; R_0402_1005Metric; LCSC C25900
Reset2: Reset; SW_Push_1P1T_XKB_TS-1187A; MNF PART NUMBER C318884; LCSC C318884
U1, U3, U4, U5, U6, U7: TMC2209_SILENTSTEPSTICK; MODULE_TMC2209_SILENTSTEPSTICK; PARTREV 1.20
U2: LM2596S-3.3; TO-263-5_TabPin3; LCSC C42421958
U8: LM2596S-5; TO-263-5_TabPin3; LCSC C42421959
U9: USBLC6-2SC6; SOT-23-6; LCSC C7519
Y2: 8MHz; Crystal_SMD_5032-2Pin_5.0x3.2mm; LCSC C115962

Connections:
+5V: C30.1, J16.1, J29.1, J30.2, J31.1, L2.2, U8.4 (FB)
/+3V3: C2.1, C8.1, C9.1, C11.1, C12.2, C13.1, C14.2, C15.1, C16.1, C17.2, C18.2, C19.1, C20.1, C22.1, C24.1, C26.1, C32.1, C33.1, C34.1, CARD1.4 (VDD), Flash1.1, IC1.6 (VBAT), IC1.11 (VDD_1), IC1.19 (VDD_2), IC1.21 (VREF+), IC1.22 (VDDA), IC1.28 (VDD_3), IC1.50 (VDD_4), IC1.75 (VDD_5), IC1.100 (VDD_6), J9.1, J19.1, J20.1, J21.1, J24.1, J25.4, L1.2, R2.1, R5.2, R8.2, R11.2, R14.2, R17.2, R20.2, R39.2, R40.2, R41.2, R42.2, R43.2, R44.2, R45.2, R46.2, R47.2, R48.2, U1.2 (VIO), U2.4 (FB), U3.2 (VIO), U4.2 (VIO), U5.2 (VIO), U6.2 (VIO), U7.2 (VIO)
/+24V_BED: J14.2, J27.1, J34.1
/+24V_MAIN: C1.1, C7.1, C10.1, C21.1, C23.1, C25.1, C27.1, C31.1, J8.1, J10.1, J11.1, J12.1, J13.1, J26.1, J28.1, U1.8 (VM), U2.1 (VIN), U3.8 (VM), U4.8 (VM), U5.8 (VM), U6.8 (VM), U7.8 (VM), U8.1 (VIN)
/BEEP: IC1.5 (PE6), J31.10
/BLUE: IC1.52 (PB13), J31.3
/BOOT0: Flash1.2, IC1.94 (BOOT0), J29.6, R1.2
/BTN_EN1: IC1.17 (PC2), J32.8
/BTN_EN2: IC1.16 (PC1), J32.6
/BTN_ENC: IC1.55 (PD8), J31.9
/CARD_DETECT: CARD1.CD, D8.2 (A2), IC1.82 (PD1), R46.1
/CD: IC1.15 (PC0), J32.4
/D+: J1.3 (D+), U9.1 (I/O1)
/D-: J1.2 (D-), U9.3 (I/O2)
/DIAG_E: IC1.44 (PE13), U6.18 (DIAG)
/DIAG_X: J23.1, U4.18 (DIAG)
/DIAG_Y: J18.1, U1.18 (DIAG)
/DIAG_Y2: IC1.39 (PE8), U7.18 (DIAG)
/DIAG_Z: J22.1, U3.18 (DIAG)
/DIAG_Z2: IC1.57 (PD10), U5.18 (DIAG)
/E_DIR: IC1.51 (PB12), R15.1, U6.9 (DIR)
/E_EN: IC1.43 (PE12), R17.1, U6.16 (~EN)
/E_STEP: IC1.46 (PE15), R16.1, U6.10 (STEP)
/E_UART: IC1.45 (PE14), U6.12 (UART)
/FAN_2: IC1.34 (PC5), R27.2
/FAN_3: IC1.36 (PB1), R25.2
/FAN_4: IC1.37 (PB2), R33.2
/FIL_RUNOUT: IC1.1 (PE2), J20.3
/GREEN: IC1.2 (PE3), J31.4
/HEAT_BED: IC1.95 (PB8), R29.2
/HEAT_EXTRUDER: IC1.35 (PB0), R22.2
/KILL: J32.1
/LASER_PWM: IC1.91 (PB5), J34.3
/LCD_A0: IC1.54 (PB15), J31.7
/LCD_CS: IC1.4 (PE5), J31.8
/LCD_RST: IC1.3 (PE4), J31.6
/M1A_E: J6.2, U6.4 (M1A)
/M1A_X: J2.2, U4.4 (M1A)
/M1A_Y: J3.2, U1.4 (M1A)
/M1A_Y2: J7.2, U7.4 (M1A)
/M1A_Z1: J4.2, U3.4 (M1A)
/M1A_Z2: J5.2, U5.4 (M1A)
/M1B_E: J6.1, U6.3 (M1B)
/M1B_X: J2.1, U4.3 (M1B)
/M1B_Y: J3.1, U1.3 (M1B)
/M1B_Y2: J7.1, U7.3 (M1B)
/M1B_Z1: J4.1, U3.3 (M1B)
/M1B_Z2: J5.1, U5.3 (M1B)
/M2A_E: J6.4, U6.5 (M2A)
/M2A_X: J2.4, U4.5 (M2A)
/M2A_Y: J3.4, U1.5 (M2A)
/M2A_Y2: J7.4, U7.5 (M2A)
/M2A_Z1: J4.4, U3.5 (M2A)
/M2A_Z2: J5.4, U5.5 (M2A)
/M2B_E: J6.5, U6.6 (M2B)
/M2B_X: J2.5, U4.6 (M2B)
/M2B_Y: J3.5, U1.6 (M2B)
/M2B_Y2: J7.5, U7.6 (M2B)
/M2B_Z1: J4.5, U3.6 (M2B)
/M2B_Z2: J5.5, U5.6 (M2B)
/NEOPIXEL: IC1.92 (PB6), R50.1
/NRST: C35.1, IC1.14 (NRST), J29.5, J32.3, R2.2, Reset2.2
/OSC_IN: C6.1, IC1.12 (PH0), Y2.2
/OSC_OUT: C5.1, IC1.13 (PH1), Y2.1
/PROBE_IN: IC1.33 (PC4), R24.1
/PROBE_SERVO: IC1.26 (PA3), J30.3
/RED: IC1.53 (PB14), J31.5
/RPI_RX: IC1.48 (PB11), J29.3
/RPI_TX: IC1.47 (PB10), J29.4
/SD_CS: CARD1.1 (CD/DAT3), D4.2 (A2), IC1.81 (PD0), R41.1
/SD_MISO: CARD1.7 (DAT0), D7.2 (A2), IC1.79 (PC11), R47.1
/SD_MOSI: CARD1.2 (CMD), D5.2 (A2), IC1.80 (PC12), R42.1
/SD_SCK: CARD1.5 (CLK), D6.2 (A2), IC1.78 (PC10), R43.1
/SPI_CS: IC1.29 (PA4), J19.3
/SPI_MISO: IC1.31 (PA6), J19.5, J32.10
/SPI_MOSI: IC1.32 (PA7), J19.6, J32.5
/SPI_SCK: IC1.30 (PA5), J19.4, J32.9
/SS: IC1.18 (PC3), J32.7
/SWCLK: IC1.76 (PA14), J25.1
/SWDIO: IC1.72 (PA13), J25.2
/TH_BED: C29.2, IC1.25 (PA2), J17.1, R40.1
/TH_EXTRUDER: C28.2, IC1.24 (PA1), J15.1, R39.1
/TH_EXTRUDER2: C36.2, IC1.23 (PA0), J33.1, R48.1
/USB_D+: IC1.71 (PA12), U9.6 (I/O1)
/USB_D-: IC1.70 (PA11), U9.4 (I/O2)
/X_DIR: IC1.61 (PD14), R4.1, U4.9 (DIR)
/X_EN: IC1.64 (PC7), R5.1, U4.16 (~EN)
/X_STEP: IC1.62 (PD15), R3.1, U4.10 (STEP)
/X_STOP: IC1.65 (PC8), J9.2, J23.2
/X_UART: IC1.63 (PC6), U4.12 (UART)
/Y2_DIR: IC1.42 (PE11), R18.1, U7.9 (DIR)
/Y2_EN: IC1.38 (PE7), R20.1, U7.16 (~EN)
/Y2_STEP: IC1.41 (PE10), R19.1, U7.10 (STEP)
/Y2_UART: IC1.40 (PE9), U7.12 (UART)
/Y_DIR: IC1.84 (PD3), R6.1, U1.9 (DIR)
/Y_EN: IC1.87 (PD6), R8.1, U1.16 (~EN)
/Y_STEP: IC1.85 (PD4), R7.1, U1.10 (STEP)
/Y_STOP: IC1.88 (PD7), J18.2, J21.2
/Y_UART: IC1.86 (PD5), U1.12 (UART)
/Z1_DIR: IC1.66 (PC9), R9.1, U3.9 (DIR)
/Z1_EN: IC1.69 (PA10), R11.1, U3.16 (~EN)
/Z1_STEP: IC1.67 (PA8), R10.1, U3.10 (STEP)
/Z1_UART: IC1.68 (PA9), U3.12 (UART)
/Z2_DIR: IC1.60 (PD13), R12.1, U5.9 (DIR)
/Z2_EN: IC1.56 (PD9), R14.1, U5.16 (~EN)
/Z2_STEP: IC1.59 (PD12), R13.1, U5.10 (STEP)
/Z2_UART: IC1.58 (PD11), U5.12 (UART)
/Z_STOP: IC1.83 (PD2), J22.2, J24.2
GND: C1.2, C2.2, C3.1, C4.2, C5.2, C6.2, C7.2, C8.2, C9.2, C10.2, C11.2, C12.1, C13.2, C14.1, C15.2, C16.2, C17.1, C18.1, C19.2, C20.2, C21.2, C22.2, C23.2, C24.2, C25.2, C26.2, C27.2, C28.1, C29.1, C30.2, C31.2, C32.2, C33.2, C34.2, C35.2, C36.1, CARD1.3 (Vss1), CARD1.6 (Vss2), CARD1.12, CARD1.13, D1.2 (A), D2.2 (A), D3.1 (K), D4.1 (A1), D5.1 (A1), D6.1 (A1), D7.1 (A1), D8.1 (A1), H5.1 (1_1), H6.1 (1_1), H7.1 (1_1), H8.1 (1_1), IC1.10 (VSS_1), IC1.20 (VSSA), IC1.27 (VSS_2), IC1.74 (VSS_3), IC1.99 (VSS_4), J1.4 (GND), J1.5 (Shield), J9.3, J10.2, J11.2, J12.2, J15.2, J16.2, J17.2, J19.2, J20.2, J21.3, J24.3, J25.3, J27.2, J29.2, J30.1, J30.4, J31.2, J32.2, J33.2, J34.2, Q1.3, Q2.3, Q3.3, Q4.3, Q5.3, R1.1, R3.2, R4.2, R6.2, R7.2, R9.2, R10.2, R12.2, R13.2, R15.2, R16.2, R18.2, R19.2, R21.2, R26.2, R28.2, R30.2, R34.2, Reset2.1, U1.1 (GND), U1.7 (GND), U2.3 (GND), U2.5 (~ON/OFF), U3.1 (GND), U3.7 (GND), U4.1 (GND), U4.7 (GND), U5.1 (GND), U5.7 (GND), U6.1 (GND), U6.7 (GND), U7.1 (GND), U7.7 (GND), U8.3 (GND), U8.5 (~ON/OFF), U9.2 (GND)
unnamed: CARD1.8 (DAT1), R44.1
unnamed: CARD1.9 (DAT2), R45.1
unnamed: D1.1 (K), L1.1, U2.2 (OUT)
unnamed: D2.1 (K), L2.1, U8.2 (OUT)
unnamed: D3.2 (A), R23.1
unnamed: C3.2, IC1.49 (VCAP_1)
unnamed: C4.1, IC1.73 (VCAP_2)
unnamed: J1.1 (VBUS), R23.2, U9.5 (VBUS)
unnamed: J8.2, Q1.4
unnamed: J13.2, Q4.4
unnamed: J14.1, Q5.4
unnamed: J16.3, R50.2
unnamed: J26.2, Q2.4
unnamed: J28.2, Q3.4
unnamed: J30.5, R24.2
unnamed: Q1.1, R21.1, R22.1
unnamed: Q2.1, R25.1, R26.1
unnamed: Q3.1, R33.1, R34.1
unnamed: Q4.1, R27.1, R28.1
unnamed: Q5.1, R29.1, R30.1

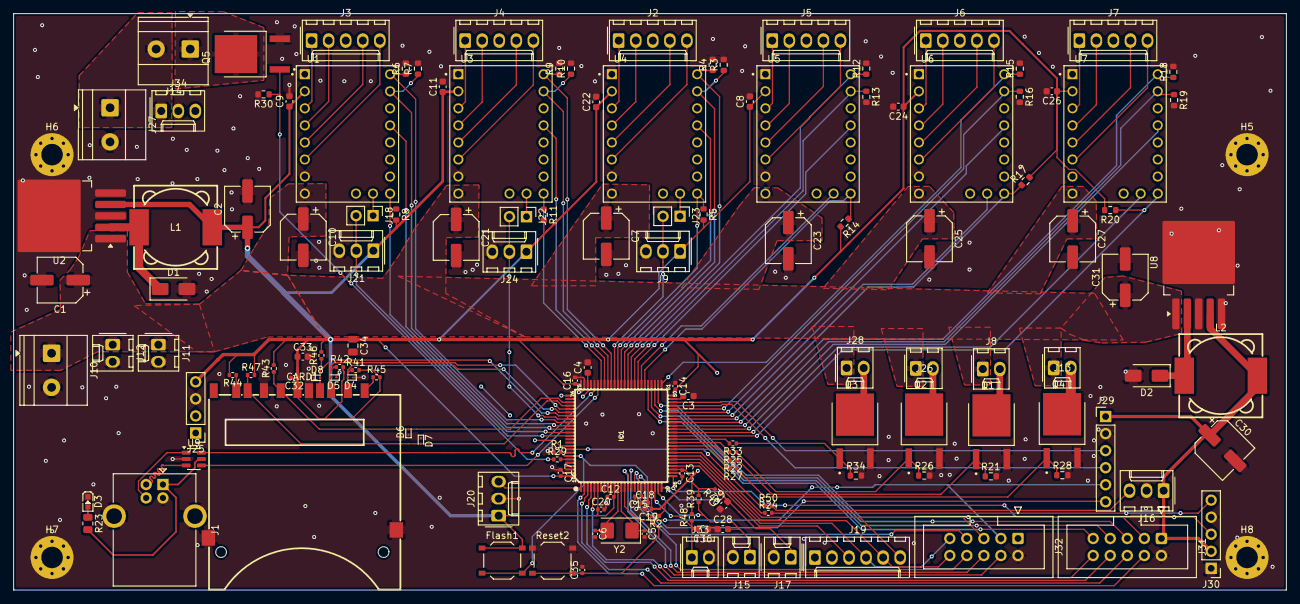
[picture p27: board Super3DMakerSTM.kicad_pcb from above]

Board: 4 copper layers, 189.6 x 85.9 mm, 146 parts (0 on the bottom side), 128 nets.

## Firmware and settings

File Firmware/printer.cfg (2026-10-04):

# This is the configuration file for klipper software
# Once the STM32 is flashed and connected to the Raspberry Pi via SERIAL,
# you must SSH into the Pi and run the following command to find your unique MCU ID
# ls /dev/serial/by-id/*
# Then copy the output and replace the serial path below with your specific ID

# PROFI3DMAKER - CUSTOM STM32F407VET6 MOTHERBOARD CONFIGURATION

[include mainsail.cfg]

[printer]
kinematics: cartesian
max_velocity: 230
max_accel: 3000
max_z_velocity: 3
max_z_accel: 10

[mcu]
serial: /dev/ttyAMA0
baud: 250000

[force_move]
enable_force_move: True

# KROKOVÉ MOTORY A DRIVERY (TMC2209)

[stepper_x]
step_pin: PD4
dir_pin: PD3
enable_pin: !PD6
microsteps: 16
rotation_distance: 48
endstop_pin: ^PD2
position_endstop: 0
position_max: 400
full_steps_per_rotation: 400

[tmc2209 stepper_x]

uart_pin: ^PD5
run_current: 0.800
stealthchop_threshold: 999999


[stepper_y]

step_pin: PA8
dir_pin: !PC9
enable_pin: !PA10
microsteps: 16
rotation_distance: 48
#endstop_pin: probe:z_virtual_endstop
endstop_pin: ^PD7
position_endstop: 0
position_max: 260
position_min: -2
full_steps_per_rotation: 400


[tmc2209 stepper_y]
uart_pin: ^PA9
run_current: 0.800
stealthchop_threshold: 999999

[stepper_y1]
step_pin: PD12
dir_pin: !PD13
enable_pin: !PD9
microsteps: 16
rotation_distance: 48
full_steps_per_rotation: 400

[tmc2209 stepper_y1]
uart_pin: ^PD11
run_current: 0.800
stealthchop_threshold: 999999


[stepper_z]
step_pin: PD15
dir_pin: PD14
enable_pin: !PC7
microsteps: 16          
rotation_distance: 3
full_steps_per_rotation: 200
endstop_pin: ^PC8
position_endstop: 0        
position_max: 190
position_min: -5

[tmc2209 stepper_z]
uart_pin: ^PC6
run_current: 0.6      
#interpolate: True     
stealthchop_threshold: 999999


[stepper_z1]
step_pin: PE10
dir_pin: PE11
enable_pin: !PE7
microsteps: 16        
rotation_distance: 3
full_steps_per_rotation: 200

[tmc2209 stepper_z1]
uart_pin: ^PE9
diag_pin: ^PE8
run_current: 0.6    
#interpolate: True
stealthchop_threshold: 999999

[extruder]
step_pin: PE15
dir_pin: PB12
enable_pin: !PE12
microsteps: 16
rotation_distance: 33.93
nozzle_diameter: 0.500
filament_diameter: 1.750
heater_pin: PB0
sensor_type: ATC Semitec 104NT-4-R025H42G
sensor_pin: PA1
control: pid
pid_kp: 22.2
pid_ki: 1.08
pid_kd: 114
min_temp: -100
max_temp: 250
full_steps_per_rotation: 400

[tmc2209 extruder]
uart_pin: ^PE14
diag_pin: ^PE13
run_current: 0.800
stealthchop_threshold: 999999

# VYHŘÍVANÁ PODLOŽKA

[heater_bed]
heater_pin: PB8
sensor_type: ATC Semitec 104NT-4-R025H42G
sensor_pin: PA2
control: pid
pid_kp: 54.027
pid_ki: 0.770
pid_kd: 948.182
min_temp: -100
max_temp: 100

# VENTILÁTORY

[fan_generic test_fan2]
pin: PB9

[heater_fan hotend_fan]
pin: PB1

[fan]
pin: PB7

# Z-SONDA CR-TOUCH 

[bltouch]
sensor_pin: ^PC4
control_pin: PA3
x_offset: -22.1
y_offset: -41.25
z_offset: 0
probe_with_touch_mode: True

#[safe_z_home]
#home_xy_position: 200, 130
#speed: 50
#z_hop: 10
#z_hop_speed: 5

#[z_tilt]
#z_positions:
#    -50, 10
#    200, 300
#    450, 10
#points:
#    50, 50
#    200, 210
#    350, 50
#speed: 100
#horizontal_move_z: 10

# ADXL345 

[mcu accel]
serial: /dev/serial/by-id/usb-Klipper_rp2040_50443404188A101C-if00

[lis2dw]
cs_pin: accel:gpio9
spi_software_sclk_pin: accel:gpio10
spi_software_mosi_pin: accel:gpio11
spi_software_miso_pin: accel:gpio8
axes_map: x,y,z

[resonance_tester]
accel_chip: lis2dw
probe_points:
    200, 130, 20

# DISPLEJ A UŽIVATELSKÉ ROZHRANÍ


#[display]
#lcd_type: st7789v
#cs_pin: PE5
#dc_pin: PB15
#reset_pin: PE4
#encoder_pins: ^PC2, ^PC1
#click_pin: ^!PD8

#[beeper]
#pin: PE6


# SENZOR FILAMENTU


[filament_switch_sensor fil_runout]
switch_pin: ^PE2
pause_on_runout: True

# LED OSVĚTLENÍ A LASER

[neopixel my_neopixel]
pin: PB6
chain_count: 1
color_order: GRB
initial_RED: 1.0
initial_GREEN: 1.0
initial_BLUE: 1.0

[output_pin LED_RED]
pin: PB14
pwm: True

[output_pin LED_GREEN]
pin: PE3
pwm: True

[output_pin LED_BLUE]
pin: PB13
pwm: True

[output_pin laser_pwm]
pin: PB5
pwm: True

# ZÁLOŽNÍ TERMISTOR

[temperature_sensor extra_thermistor]
sensor_type: ATC Semitec 104NT-4-R025H42G
sensor_pin: PA0

#SD KARTA - NENÍ MOŽNÉ POUŽÍT, PROTOŽE TO KLIPPER NEPODPORUJE - DAVAL JSEM TO TAM ZBYTECNE

#[sdcard]
#spi_software_sclk_pin: PC10
#spi_software_mosi_pin: PC12
#spi_software_miso_pin: PC11
#cs_pin: PD0

[verify_heater heater_bed]
max_error: 999999
check_gain_time: 999

[bed_mesh]
speed: 150
horizontal_move_z: 6
mesh_min: 30, 50        
mesh_max: 330, 180      
probe_count: 5, 5       
algorithm: bicubic

#*# <---------------------- SAVE_CONFIG ---------------------->
#*# DO NOT EDIT THIS BLOCK OR BELOW. The contents are auto-generated.
#*#
#*# [input_shaper]
#*# shaper_type_x = 2hump_ei
#*# shaper_freq_x = 53.4
#*# shaper_type_y = mzv
#*# shaper_freq_y = 33.2

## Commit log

2026-05-17 Enhance README with project details and BOM
    Expanded project description and added detailed features, BOM, and assembly information.
2026-05-17 Rename Snímek obrazovky 2026-05-17 124707.png to schematics.png
2026-05-17 Rename Snímek obrazovky 2026-05-17 125100.png to pcb_b.png
2026-05-17 Rename Snímek obrazovky 2026-05-17 125039.png to pcb_f.png
2026-05-17 Rename Snímek obrazovky 2026-05-17 125022.png to pcb_in1.png
2026-05-17 Rename Snímek obrazovky 2026-05-17 124927.png to pcb_in2.png
2026-05-17 Rename Snímek obrazovky 2026-05-17 124850.png to pcb_b22.png
2026-05-17 Rename Snímek obrazovky 2026-05-17 124820.png to pcb_f2.png
2026-05-17 Update README with KiCad version and klipper details
    Updated KiCad version from 8 to 10 and corrected 'klipper' capitalization.
2026-05-17 Enhance README with project explanation and formatting
    Added project background and details about reverse-engineering the old board. Updated section headers and improved formatting.
2026-07-15 Document Super3DMaker project details and BOM
    Added detailed project description, features, gallery, and bill of materials for the Super3DMaker Controller Board.
2026-10-03 Revise printer.cfg for STM32F407VET6 configuration
    Updated printer configuration for custom STM32F407VET6 motherboard, including changes to stepper motors, MCU settings, and additional features.
    [printer.cfg]
2026-10-03 Enhance gallery with build preview and printing images
    Added build preview and printing images to the gallery section.
2026-10-03 Expand README with build details and limitations
    Added details about the build and integration phase, results, and current limitations of the custom 3D printer mainboard project.
2026-10-03 Update README with toolhead mount installation details
    Clarified the installation process for the new toolhead mount and its implications on weight and printer disassembly.
2026-10-03 Replace build images with PCB versions
    Updated build preview images in README.md.
2026-10-04 Replace old print images with new ones
    Updated printing images in README with new filenames.
2026-10-04 Restore original configuration for klipper software
    [printer.cfg]
2026-10-04 Add firmware build and flash instructions to README
    Added instructions for building and flashing firmware for the custom controller board.
2026-10-04 Add firmware section to README
    Added firmware section detailing the use of Klipper firmware and configuration files.
2026-10-04 Update README with access information for original files
    Added a note about accessing original files for the 3D printer on the 3D Factories website.
2026-10-07 Update README with link to user attachments
    Added a link to user attachments in the Printing section.
2026-10-07 Update README with new calibration links
    Added links for LIS2DW accelerometer calibration and CR Touch Bed Mesh.
2026-10-07 Add bed section to README and update gallery
2026-10-07 Remove 'bed' section from README
2026-10-07 Add new asset link for CR Touch Bed Mesh
2026-10-07 Add CR Touch Bed Mesh link to README
2026-10-07 Update CR Touch Bed Mesh asset link in README
